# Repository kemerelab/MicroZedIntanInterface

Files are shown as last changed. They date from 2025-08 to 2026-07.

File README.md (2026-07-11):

# MicroZedIntanInterface

An FPGA data-acquisition interface for **Intan RHD2000-style neural recording chips**, built
on a **MicroZed** (Xilinx Zynq-7020) with a custom carrier PCB. The PL talks to up to two
cables of RHD2000 chips over a DDR SPI protocol; the PS streams the data over the network.

- Up to **256 channels @ 30 ksps** (two cables × 128 ch, Intan-standard 12-pin Omnetics, single + DDR).
- A user-programmable per-cable phase delay compensates for cable length.
- **TCP control** (port 0x6900 / 26880) + **UDP data stream** (port 0x6800 / 26624, ~9 MB/s per cable, ~18 MB/s at full config).
- Data path: `Intan ──SPI(DDR)──► PL ──BRAM──► (AXI CDMA) ──► PS ──UDP──► host`.

MicroZed SOMs are ~$300 (e.g. [Newark](https://www.newark.com/avnet/aes-z7mb-7z020-som-i-g-rev-h/eval-brd-32bit-fpga-arm-cortex/dp/62AJ7410)).
The [carrier PCB](pcb/KiCad-Project/) is manufactured at JLCPCB.

<p align="center">
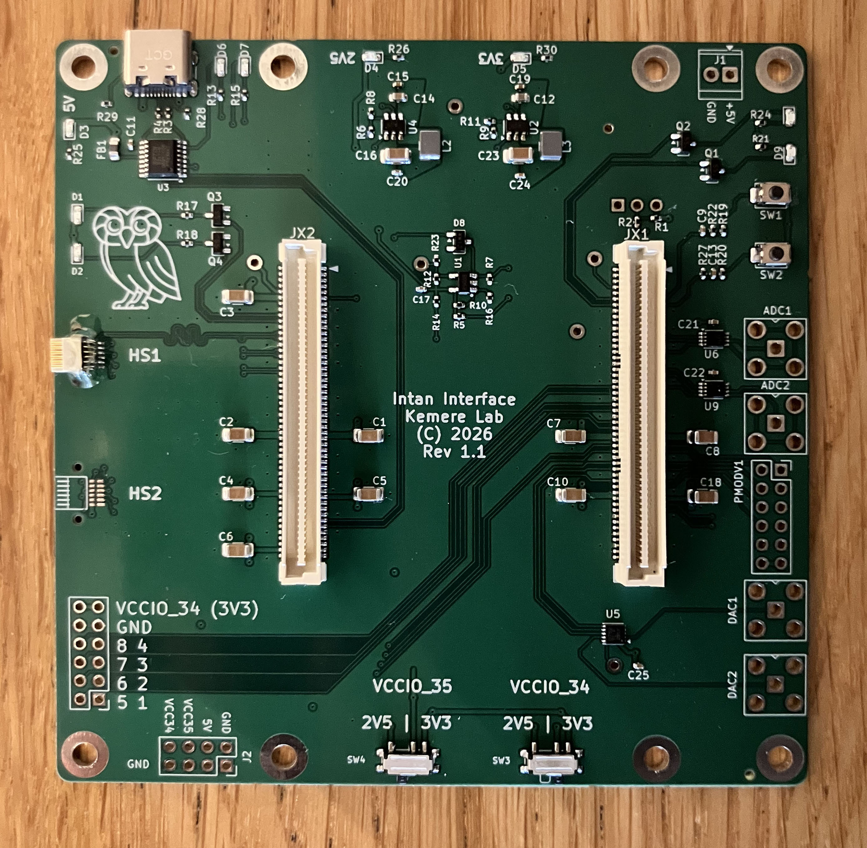
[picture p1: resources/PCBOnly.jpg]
  
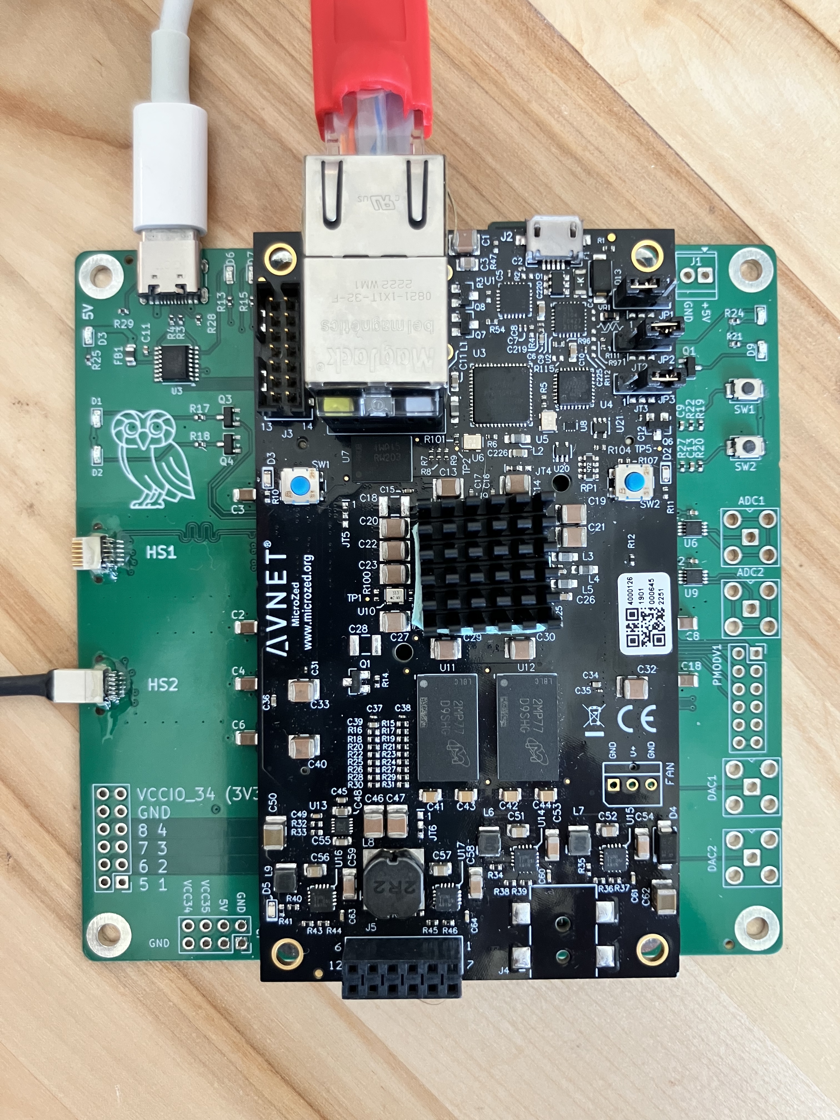
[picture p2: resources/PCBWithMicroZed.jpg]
  
</p>

## Documentation

- **[Getting up and running](docs/getting-started.md)** — assembling the board (Omnetics
  epoxy), the MicroZed boot jumpers, copying the boot image to SD, and building from source.
- **[Command & packet structure](docs/protocol.md)** — the TCP command set, the UDP packet
  format, and the register map.
- **[CLAUDE.md](CLAUDE.md)** — architecture, build commands, and conventions for developers.
- **[ROADMAP.md](ROADMAP.md)** — status and planned work. **[overview.txt](overview.txt)** —
  the deeper architectural narrative.

## Host software

The board's protocol has two reference clients (both speak TCP control + UDP capture):

- **`remote/net.py`** — a single-file Python client for bring-up, cable/phase auto-detection,
  and testing. The human-readable reference for the command set and packet format.
- **[ephys-socket](https://github.com/ckemere/ephys-socket)** — the OpenEphys GUI plugin for
  real recording and visualization (neural + aux/accelerometer channels, fast settle, banked
  aux commands).

<p align="center">
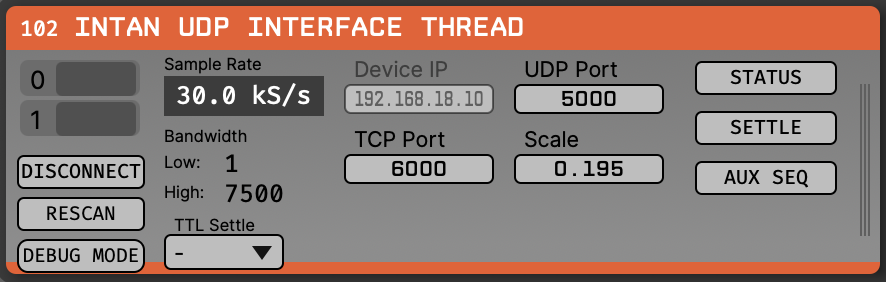
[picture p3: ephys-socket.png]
  
</p>

The firmware (`firmware/`), `remote/net.py`, and the plugin are the **three consumers of the
same register/packet contract** — keep them in sync when changing the protocol.

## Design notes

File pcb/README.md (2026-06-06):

# KiCad design files and production files

The PCB design was dervied from work by Viktor Nokolov licensed under the Creative Commons Zero license. His original project can be found here [https://github.com/viktor-nikolov/MicroZed-carrier-board](https://github.com/viktor-nikolov/MicroZed-carrier-board).

### Revision 1.1 Notes
Board revision 1.1 fixes a power supply bug in 1.0 that prevented the 3.3 and 2.5 V suppplies from workiing.
It also adds two ADCs and two DACs, connected to PL on the VCCIO-34 side.

### Revision 1.0 Notes
Board revision 1.0 fixes the bug in 0.11, and transitions from 2 layer to 4 layer fabrication. This allows for
a smaller and slightly more case-friendly layout (digital IO on the same side of the PCB as Intan/Omnetics 
connectors, and USB-C power moved to the same side as the ethernet connector).

### Revision 0.11 Notes
Board revision 0.11 was used for initial testing. There was an error in the connectivity for the USB-UART
bridge. We fixed this with a bodge that is circled in the image below.

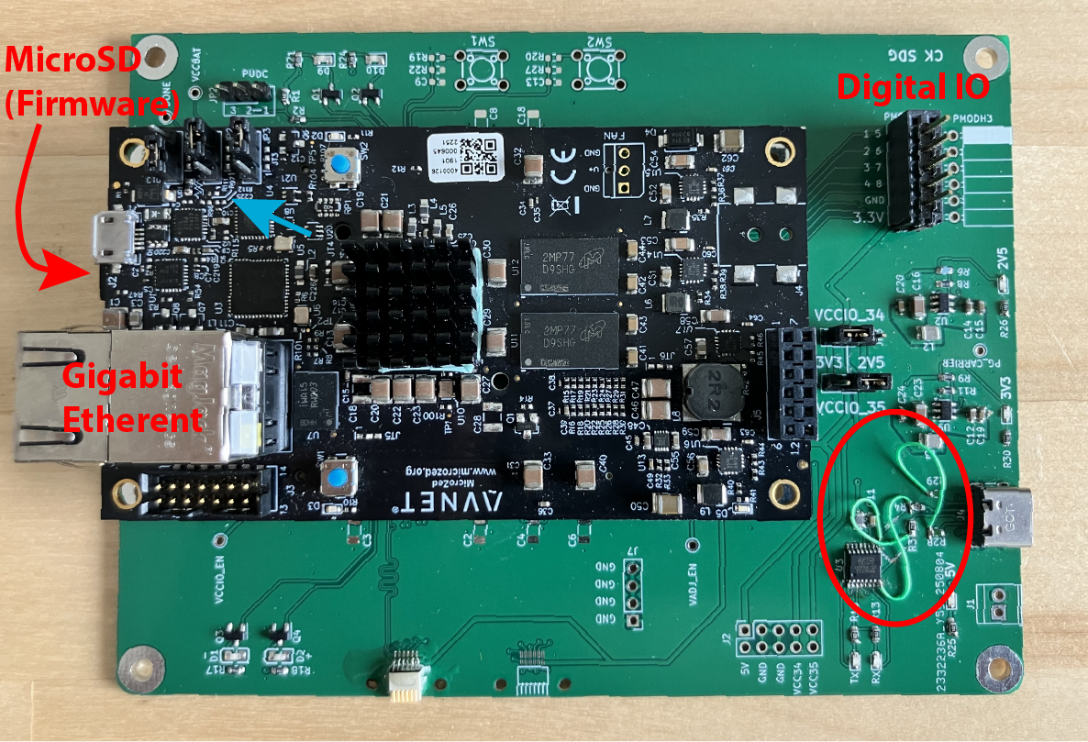
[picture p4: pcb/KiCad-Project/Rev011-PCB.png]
Revision 0.11 Manufactured PCB


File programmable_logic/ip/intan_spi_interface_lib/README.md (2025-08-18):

# Intan SPI Interface Library

This library provides custom SPI interface definitions optimized for Intan RHD chips with dual CIPO channels.
Two interface variants are available: single-ended and differential signaling.

## Interface Variants:

### 1. Single-Ended Interface (intan_spi)
- **VLNV**: kemerelab.org:intan:intan_spi:1.0
- **Signals**: sclk, csn, copi, cipo0, cipo1

### 2. Differential Interface (intan_spi_diff)  
- **VLNV**: kemerelab.org:intan:intan_spi_diff:1.0
- **Signals**: sclk_p/n, csn_p/n, copi_p/n, cipo0_p/n, cipo1_p/n

## Setup Instructions:

### 1. Add to Vivado Project:
- Open your Vivado project
- Go to Settings → IP → Repository
- Click the '+' button to add IP Repository
- Browse to and select this directory: intan_spi_interface_lib
- Click OK and Apply

### 2. Verify Installation:
After adding the repository, you should see "intan_spi_interface_lib" in the IP repositories list.

### 3. Use in Verilog Code:

#### Single-Ended Interface:
```verilog
// Intan SPI Single-Ended Interface
(* X_INTERFACE_INFO = "kemerelab.org:intan:intan_spi:1.0 intan_spi sclk" *)
output wire spi_sclk,

(* X_INTERFACE_INFO = "kemerelab.org:intan:intan_spi:1.0 intan_spi csn" *)
output wire spi_csn,

(* X_INTERFACE_INFO = "kemerelab.org:intan:intan_spi:1.0 intan_spi copi" *)
output wire spi_copi,

(* X_INTERFACE_INFO = "kemerelab.org:intan:intan_spi:1.0 intan_spi cipo0" *)
input wire spi_cipo0,

(* X_INTERFACE_INFO = "kemerelab.org:intan:intan_spi:1.0 intan_spi cipo1" *)
input wire spi_cipo1,
```

#### Differential Interface:
```verilog
// Intan SPI Differential Interface
(* X_INTERFACE_INFO = "kemerelab.org:intan:intan_spi_diff:1.0 intan_spi_diff sclk_p" *)
output wire spi_sclk_p,
(* X_INTERFACE_INFO = "kemerelab.org:intan:intan_spi_diff:1.0 intan_spi_diff sclk_n" *)
output wire spi_sclk_n,

(* X_INTERFACE_INFO = "kemerelab.org:intan:intan_spi_diff:1.0 intan_spi_diff csn_p" *)
output wire spi_csn_p,
(* X_INTERFACE_INFO = "kemerelab.org:intan:intan_spi_diff:1.0 intan_spi_diff csn_n" *)
output wire spi_csn_n,

(* X_INTERFACE_INFO = "kemerelab.org:intan:intan_spi_diff:1.0 intan_spi_diff copi_p" *)
output wire spi_copi_p,
(* X_INTERFACE_INFO = "kemerelab.org:intan:intan_spi_diff:1.0 intan_spi_diff copi_n" *)
output wire spi_copi_n,

(* X_INTERFACE_INFO = "kemerelab.org:intan:intan_spi_diff:1.0 intan_spi_diff cipo0_p" *)
input wire spi_cipo0_p,
(* X_INTERFACE_INFO = "kemerelab.org:intan:intan_spi_diff:1.0 intan_spi_diff cipo0_n" *)
input wire spi_cipo0_n,

(* X_INTERFACE_INFO = "kemerelab.org:intan:intan_spi_diff:1.0 intan_spi_diff cipo1_p" *)
input wire spi_cipo1_p,
(* X_INTERFACE_INFO = "kemerelab.org:intan:intan_spi_diff:1.0 intan_spi_diff cipo1_n" *)
input wire spi_cipo1_n,
```

### 4. Package as IP:
When you package your RTL as IP (Tools → Create and Package New IP), 
the interface annotations will cause the signals to be grouped 
into a single bus interface in block design.

## Troubleshooting:
If you get "Interface VLNV not found" errors:
1. Verify the interface library is added to IP repositories
2. Check that the XML files exist in the correct subdirectories
3. Try refreshing the IP catalog (IP Catalog → Refresh)
4. Restart Vivado if necessary

## Interface Details:
- **Purpose**: Optimized for Intan RHD neurophysiology chips
- **Features**: Dual CIPO channels for enhanced data throughput
- **Type**: Point-to-point interface (1 master, 1 slave)
- **Signaling**: Both single-ended and differential variants supported

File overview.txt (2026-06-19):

Project Overview

Using a Zynq 7000 platform, we have built a system in which the PL acquires data from an SPI-like interface, and then the PS streams it over UDP to a network destination. Control on the network side is a TCP interface. The sampling rate is 30 kHz; a packet is up to 600 bytes at the full 256-channel (two-cable) config, so the data rate is roughly 9 MB/s per cable (up to ~18 MB/s for all 256 channels).

The special SPI protocol involves having two 16 bit words of data are transmitted from the peripheral to the controller (CIPO) an interleaved way on alternative clock phases (double data rate). There are also two CIPO lines. So the whole interface is SCLK, CS, COPI, CIPO0, and CIPO1. Because of the long cables used, the MISO or CIPO data arrives with some phase delay to the clock. The PL handles this by delaying the latching of the CIPO data relative to the COPI data.

The approach that I've adopted in my verilog code for this is the following - I have a main loop with 80 states that runs at 84 MHz. This is a 4x oversampling of the SPI clock rate of 24 MHz. Data is sampled for the first 74 states into a register, and then depending on a phase variable the correctly delayed CIPO data is extracted. The data is put into a FIFO, which copies the data to a BRAM which is used to transmit this data to the PS. This code is in data_generator_core.sv and CIPO_phase_selector.v. This whole loop is repeated 35 times, so that in one data packet, 35 16-bit COPI commands are sent, and 35 x 2 (because of the double data rate) 16 bit data words are read back from each of the 2 CIPO lines. In addition, the PL sends a 64 bit packet magic header and a 64 bit timestamp, plus 64 bits of digital input (8 bits) and other metadata, plus 8 16 bit external ADC values. So one received data packet has 10 32-bit words of packet header plus the data words. The datapath has since been widened to two cables (dual-port), so the channel-enable mask selects among up to 8 streams — regular and DDR for CIPO0/CIPO1 on each of two cables. At the full 256-channel (0xFF) config that is (2 cables) x (2 CIPO lines) x (2 DDR words) x 35 commands = 280 16-bit words = 140 32-bit data words (256 amplifier channels plus per-stream aux/config readbacks), i.e. a 150-word / 600-byte maximum packet.

The PS controls the PL using an AXI Lite register interface. There are control registers which are latched from PS to PL and status registers which are latched from PL to PS. The register names are extracted in data_generator_core.sv, but the register interface is in axi_lite_registers.v. 

The PS code runs on both cores of the processor. One core is dedicated to the serial debug interface, the other core has a fast loop which does three primary tasks: processing commands which might come over from a TCP network endpoint, reading data from the BRAM, and transmitting this data through UDP to the network. The bulk BRAM read is done by an AXI CDMA (a PL bus master that copies each packet from the capture BRAM into a DDR buffer over the S_AXI_HP0 port) rather than by the CPU — this keeps the PS M_AXI_GP master, which corrupts long burst reads, off the data path. The main code files are main.c, network.c, pl_control.c, and pl_dma.c (the CDMA driver), with main.h defining things.

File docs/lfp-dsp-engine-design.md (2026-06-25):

# LFP / on-PL DSP engine — design

Status: **design** (branch `claude/pl-dsp-engine`). This is the agreed plan, not yet
implemented. It captures the first module of an on-fabric **preprocessing engine** aimed
at closed-loop work: a decimating low-pass filter that extracts an **LFP band** and streams
it as a second, independent data product.

LFP = anti-alias low-pass + downsample 30 kHz → **3 kHz** (decimation `R = 10`,
Phase A; was 2 kHz / `R = 15`). See `docs/PHASE_A_SUMMARY.md` for the 3 kHz
anti-alias design (a ~131-tap Kaiser run on a **dual-MAC** time-shared engine,
passband ~1 kHz, ≥46 dB alias rejection) and the analytic-chirp debug signal.
The single-stage budget at R=10 is ~109 taps/256ch per MAC, so the engine now
processes `N_MAC=2` taps/clock (DSP48 is otherwise free); the delay-line BRAM is
unchanged. A CIC÷5 + halfband÷2 variant (`cic_decimator.sv`/`lfp_halfband.sv`)
that would cut the delay-line BRAM ~5× is the documented alternative.

## 1. Why these choices (the short version)

| Decision | Choice | Why |
|---|---|-----|
| Where the filter runs | **PL fabric** | closed-loop needs µs latency; host round-trip is ms |
| Filter structure | **one time-shared polyphase FIR decimator** | ~22 PL clocks per input sample → 1 datapath serves all 256 ch |
| Arithmetic | 1–2 DSP48, per-channel state in BRAM | `taps × out_rate × ch` = `200×2000×256` ≈ 102 MMAC/s ≈ 1.2 DSP48 @ 84 MHz |
| Coefficients | **shared coef RAM, host-loadable via an indirect window** | one design for all channels; not 200+ registers |
| Transport | **separate UDP stream on its own port** | broadband path stays byte-identical; mirrors the Neuropixels AP/LFP split |
| PL→PS | **dedicated LFP BRAM, reuse the existing CDMA** | proven path; CDMA idle 14/15 of the time |
| Packetization | **core 0, one LFP frame per packet (no batching)** | system already sustains 30k pps; batching only enlarges the per-cycle spike and hits the MTU at K=3 |

Bandwidth: LFP is `256 × 2k × 2 B` = **1.0 MB/s** = +6.7% on top of the ~18 MB/s broadband
(the ratio is just `1/R`, invariant of channel count). The real saving comes from *not*
streaming broadband when an experiment only needs LFP (set broadband mask small / 0 →
~18× less data), which the independent-stream design makes a one-register change.

**Data fidelity:** LFP is a *derived* band on a separate wire. The raw broadband samples
are never altered — consistent with the lab's data-fidelity rule.

## 2. Datapath (PL)

```
per-channel sample stream ─► [delay-line BRAM, 256×N] ─► time-shared MAC ─► [decimate ÷R] ─► LFP frame
   (from acquisition FSM)            ▲                         ▲
                                     │                  [coef RAM, 1×N, shared]
                              write @ input rate         read 1 tap/clk
```

- **Delay lines** (the real memory cost): `256 ch × N taps × 16-bit`. For `N=256`:
  256·256·2 = 128 KB ≈ ~28 BRAM36 of 140 on the 7020 (~20%). For `N=200`: ~100 KB. If
  this ever gets tight, switch to **multi-stage** decimation (CIC ÷15 + short comp-FIR, or
  cascaded halfbands) to shrink both the tap count and the delay lines. Single-stage is the
  v1 because it is the simplest to reason about and fits.
- **Coefficient RAM**: `1 × N × 18-bit`, shared across all channels. `N≤512` is half a
  BRAM18. Dual-port: AXI-clock write side, 84-MHz read side (the BRAM *is* the CDC).
- **MAC**: one DSP48E1 (25×18 signed mult + 48-bit acc), time-shared. Sequences
  `(channel, tap)`; emits an output once per `R` input samples per channel.
- **Group delay**: linear-phase FIR → fixed `(N-1)/2 / Fs` ≈ **3.3 ms** at `N=200`. Fine
  for streaming/recording and amplitude/band-power features; a *phase-targeted* closed loop
  (theta/gamma phase-locked stim) would instead want a low-order IIR or a phase predictor —
  noted as a future module, not v1.

## 3. Coefficients — the indirect window (NOT 200 registers)

One filter design is shared by all channels, so there is exactly one coefficient table.
It lives in the coef RAM and is uploaded through a 2-register window, reusing the
**aux-bank strobe/toggle CDC pattern** already in the codebase (`CTRL_REG_AUX_WRITE` +
`CTRL_REG_AUX_STROBE`):

- write pointer auto-increments on each coefficient write;
- the host streams `N` 18-bit signed taps (one-time setup, like the COPI/aux uploads —
  trivial over TCP);
- **coefficients latch only while streaming is stopped** (matches the existing "safe
  control register" convention), so a live pass never mixes old/new taps. A ping-pong
  double-buffer for live retune is a later option, not v1.

The host owns the design: `scipy.signal.firwin`/`remez` → quantize to **Q1.17** (18-bit
signed) → upload. Thin firmware pipe, host computes the physical units — same split as
everywhere else.

## 3a. Sample representation — offset binary (critical)

Intan amplifier samples are **offset binary**: mid-scale `0x8000` = baseline (0 µV),
`V = 0.195 µV × (code − 32768)`. (This repo's debug `sine_lut` confirms it — centered at
`+32767`, "unsigned-16-bit".) The FIR engine is a **pure two's-complement signed** DSP
block, so the offset must be removed at its input and re-applied at its output, otherwise
a quiet baseline sits at the signed saturation rail and the low-pass output is a flat,
saturated line.

Conversion is a symmetric **MSB invert** (`^ 0x8000`), done at the integration boundary so
the engine stays generic and already-proven:
- **in:** `engine_sample = raw_sample ^ 0x8000`  (offset binary → signed, centered at 0)
- **out:** `lfp_sample = engine_out ^ 0x8000`     (signed → offset binary)

LFP is therefore shipped in the **same offset-binary format as broadband**, so the host
de-offsets both identically. The raw broadband stream is untouched (data fidelity).

**Channels filtered = the 32 amplifier converts only** (8 lanes × 32 = 256 ch). The
integration tap drops the 3 aux slots *and* removes the 2-cycle SPI readback offset:
`convert_cmd_sequence` issues CONVERT(0..31) at command-slots 0–31, so with the +2 readback
delay the amplifier samples land at `cycle_counter` 2..33 → fed as engine slot 0..31
(slots 0/1/34 carry aux/wrap and are not fed). This makes the delay line exactly 8×32×N
(not 8×35×N), the ~128 KB / ~32 BRAM36 in §2.

Bonus: debug-mode sine (58–469 Hz, all < 600 Hz) passes the LP filter, so it is a clean
on-bench LFP test signal through this path.

## 4. Contract additions (the three layers)

### 4a. Commands (host → PS), new `0x80` block

| ID | Name | params | notes |
|----|---|---|---|
| `0x80` | `LFP_ENABLE` | p1 = 0/1 | enable/disable the LFP engine + stream |
| `0x81` | `LFP_SET_PARAMS` | p1 = decimation `R`; p2 = `num_taps` | latched while stopped |
| `0x82` | `LFP_SET_CHANNELS` | p1 = 8-bit stream mask | independent of the broadband mask |
| `0x83` | `LFP_WRITE_COEF` | p1 = index (or auto-inc); p2 = 18-bit signed tap | maps to the coef window + strobe |
| `0x84` | `LFP_SET_UDP_PORT` | p1 = port | default 5001 |
| `0x85` | `LFP_DUMP_COEF` | — | optional: read back the loaded table for verification |

### 4b. Control registers (PS → PL), extend past the aux regs (reg 25+)

`PL_N_CTRL_REGS` grows from 25. New regs (indices fixed at implementation):

- `CTRL_REG_LFP_PARAMS` — `[0]` lfp_en, `[15:8]` lfp_stream_mask, `[23:16]` decimation `R`,
  `[31:24]` num_taps (latched while inactive).
- `CTRL_REG_LFP_COEF_ADDR` — write pointer into the coef RAM (read back = current pointer).
- `CTRL_REG_LFP_COEF_DATA` — `[17:0]` tap value; a write stores `coef[ptr]`, `ptr++`
  (crosses to the 84-MHz domain via the aux-style strobe toggle).

> Note: adding control regs moves `STATUS_REG_BASE` (`= PL_N_CTRL_REGS*4`). The binary
> `GET_STATUS` path is index-agnostic so it is unaffected; only raw register peeks shift.

### 4c. get_status (PL/PS → host) — "report everything configurable"

`status_response_t` carries (see `firmware/include/main.h`):

- `lfp_enable`, `lfp_decim_R`, `lfp_lane_mask`, `lfp_num_taps`, `lfp_packets_sent`, `lfp_overrun`.
- `lfp_lane_mask` is reported as the **broadband `channel_enable` mask** (the single source of
  truth) — `network.c::collect_status_data` fills it from `pl_get_current_channel_enable()`,
  not from a separate LFP mask register.

### 4d. LFP UDP packet (board → host, port 5001) — **PL-built, DMA'd into the pbuf**

Compact, self-describing, its own magic so a misrouted packet is caught. **The PL builds the
complete wire packet (6-word header + decimated samples) in the LFP output BRAM** — exactly
the broadband pattern where `data_generator_core.sv` writes the 10-word header into the
capture BRAM. The PS then just **CDMAs the whole frame straight into a pbuf and sends it**
(`network.c::lfp_stream_service` → `pl_dma_read_addr` from `0x84000000` into a non-cacheable
LFP staging buffer → `udp_sendto` a `PBUF_REF`). **No PS-side header construction, no
`Xil_In32` sample loop** (`scripts/check_dma.sh` enforces this — the LFP single-beat loop is
gone). Implemented layout (one frame = one wire packet):

| words | field | notes |
|---:|---|---|
| 0 | magic low `0x1F1FBEEF` | distinct low word vs broadband's `0xDEADBEEF` |
| 1 | magic high `0xCAFEBABE` | |
| 2–3 | 64-bit master **timestamp** | the master count of the **newest broadband sample in this output's decimation window** — i.e. the most recent broadband packet that was clocked into the filter bank for this output. The decimating filters are just FIR: when one emits an output, exactly one real, already-acquired broadband sample is the newest input in that output's support, and this is its master count (the *same* counter the broadband header stamps, word 1). For frame `m` at total decimation `R` it is broadband packet `R·m + (R−1)` (e.g. R=10 → `10m+9`). Causal, monotonic, `R` apart — an **absolute master timestamp**, not a frame index. (See "timestamp accounting" below for the CIC→halfband bookkeeping.) |
| 4 | `[7:0]` lane_mask · `[15:8]` decim_R · `[23:16]` num_taps · `[31:24]` overrun | `lane_mask` = the **broadband `channel_enable` mask** (single source of truth; see below) |
| 5 | 32-bit sequence number | PL-maintained LFP frame counter (++ per emitted frame), for drop detection |
| 6… | payload: enabled lanes × 32 ch × 16-bit, offset-binary (2 per word) | `0xFF` → 256 ch = 128 words |

**Lane mask = broadband mask.** The LFP engine's `lane_mask` is driven from the broadband
`channel_enable_reg` (`data_generator_core.sv` → `dsp_channel_enable` → `lfp_dsp_block`), **not**
from `lfp_cfg[15:8]`. The LFP filters exactly the broadband-enabled lanes — one place to pick
streams (`set_channels`). `CMD_LFP_SET_CHANNELS` is deprecated (firmware accepts-and-ignores).

**Timestamp accounting (CIC→halfband).** The chain is CIC(/5) → halfband(/2) = /10, each a
decimating FIR. Trace one output's *newest input* through the cascade:
- The CIC emits an output frame on every 5th broadband `packet_tick` (`run_comb` when
  `decim_cnt` wraps at R=5), so CIC output `k` has newest broadband packet `5k+4`.
- The halfband ingests one sample per CIC output and emits on every 2nd one (`decim_phase`),
  so halfband output `m` has newest CIC input = CIC output `2m+1`, i.e. newest broadband
  packet `5·(2m+1)+4 = 10m+9`.

`lfp_dsp_block` keeps a single register `ts_ingest`, updated to `(master_timestamp − 1)` on
**every** broadband `packet_tick` (the live counter has already incremented to "just-finished
packet + 1" on that edge, so `−1` is the count the broadband header carries for that packet).
On `frame_tick` (the halfband's decimation tick / `start_pass`) it snapshots `ts_ingest` into
the header. The cascade latency from "packet `10m+9` closes the window" to "`frame_tick` fires"
(CIC comb pass + glue replay) is a few hundred clk — far less than the ~2800-clk broadband
packet period — so **no new `packet_tick` arrives in between**, and the snapshot is exactly
`10m+9`. (If the engine ever fell a frame behind under load, `compute_overrun` latches and is
reported in header word 4 bit 24.)

**Host alignment.** The stamp marks *which broadband sample is the newest one folded into this
LFP value* — it is **not** the instant the LFP value represents. A linear-phase anti-alias
filter's output is centered earlier than its newest input by the chain's **group delay** (a
fixed, known number of broadband samples). To align an LFP sample with the broadband stream's
*content*, subtract that group delay; to align with *which input data has been seen*, use the
stamp directly. The plugin exposes this as a second ~3 kHz DataStream (`A_LFP1…`, `B_LFP1…`),
alongside the 30 kHz broadband stream.

## 5. PL plumbing summary

Reuses proven parts; the only new RTL is the filter:

1. **+1 BRAM** — small LFP ring (a few KB), written by the DSP engine (kept separate from
   the `0x80000000` capture BRAM to isolate the two write paths).
2. **+1 `axi_bram_ctrl`** at a new address (e.g. `0x84000000`), added as a 3rd slave on
   `smartconnect_1` (2×2 → 2×3) — a copy of the existing pattern.
3. **Reuse the one CDMA** — broadband transfer every 33.3 µs cycle (as today) + an LFP
   transfer on the 1-in-`R` cycle (different `SRCADDR`). Single engine, sequenced, no
   contention (LFP duty 1/decim, each transfer a few µs). The LFP output BRAM
   (`0x84000000` / `axi_bram_ctrl_1`) is in the `axi_cdma_0/Data` address space
   (`design_1_bd.tcl`) so the CDMA can read it; `pl_dma_read_addr(dst, src_addr, n)`
   generalizes the read to an arbitrary BRAM source.
4. **+1 `XAxiCdma_SimpleTransfer`** call (the whole PL-built packet, header + samples) →
   zero-copy `udp_sendto` in the core-0 loop. The PS adds **no** header and copies **no**
   samples on the CPU.

## 6. Out of scope for v1 (future engine modules)

- Multi-stage (CIC + comp-FIR) decimation if BRAM/taps get tight or more bands are added.
- IIR / phase-predictor path for phase-targeted closed loop.
- Live coefficient retune (ping-pong double-buffer).
- Core-1 as a data engine — only worth it bundled with moving serial debug to a **soft
  core** (the EMAC is a single core-0-owned peripheral and bare-metal lwIP is single-
  instance, so core 1 can't independently transmit; parked).
- On-fabric feature extraction (band power, threshold crossings, phase) feeding a control
  output — the actual closed-loop endgame this engine is built toward.

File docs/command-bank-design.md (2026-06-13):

# Design — Aux Command Bank Rebuild + Fast-Settle/Digout Override

**Status:** Converged design (June 2026). Confirm chip details against
`docs/Intan_RHD2000_series_datasheet.pdf` / `docs/Intan_RHD2164_datasheet.pdf` before implementing.
Reference implementation studied: `github.com/open-ephys/rhythm` + `open-ephys-plugins`
(clones under `~/Code/Intan/`).

## Motivation

Today the streaming command stream is a flat, fixed 35-entry list replayed identically every
packet (`pl_control.c: convert_cmd_sequence`, played out by `data_generator_core.sv` over
`cycle_counter` 0..34). The three aux positions are static `CONVERT(32/33/34)`, leaving no room —
without a firmware rebuild — for temperature, supply, runtime link/health checks, impedance,
ad-hoc register access, real-time digital output, or fast settle.

This rebuild replaces the static aux positions with **programmable, looping, swappable per-slot
command banks**, adds a **real-time override layer** (fast settle + digital-out + a Register-3
shadow), and uses **PL-side frame alignment with command-echo identity** so the host receives
clean, self-contained UDP packets.

## Command source model

Per packet (= one ~30 kHz sample) the PL issues 35 commands: 32 channel converts + 3 aux.
A host-writable **full 35-entry command table** remains the base; two enable bits overlay the
segmented behavior:

```
if (cycle_counter < 32)
    cmd = auto_convert_en ? make_convert(cycle_counter)    // CONVERT(pos), fixed every packet
                          : full_cmd_table[cycle_counter]; // host table (init/cal/cable-test)
else begin
    slot = cycle_counter - 32;                              // 0,1,2
    cmd = aux_bank_en ? aux_slot[slot].read()              // looping per-slot bank
                      : full_cmd_table[cycle_counter];
end
// → override layer (below) may rewrite cmd
```

| Mode | `auto_convert_en` | `aux_bank_en` | `loop_count` | Behavior |
|---|---|---|---|---|
| Init / calibrate / cable-test | 0 | 0 | 1..N | full table replayed (today's exact pipeline) |
| Acquisition | 1 | 1 | 0 (∞) | auto converts + looping aux banks + overrides |

The segmentation is a **two-index-domain** FSM: positions 0–31 indexed by `cycle_counter` (fixed
each packet); positions 32–34 indexed by **per-slot, per-packet indices** that loop independently.

## Storage: 3 independent per-slot command BRAMs

One **dual-port BRAM per aux slot** (3 total) — *not* one shared 3×N array — so each slot's index,
length, and bank-select are fully independent (Slot 2 loops at 3, Slot 3 at ~30; trivial with
separate RAMs). Each BRAM is its own AXI **memory-mapped window** (PS writes as memory; FPGA reads
on the PL clock), separate from the control registers and the data BRAM.

- **≥2 banks per slot** (active + standby), so you write a standby bank while the FSM reads the
  active one — no torn program.
- **Length is bound to the bank.** Each bank carries its own `(loop_idx, end_idx)`, so a
  bank-select **atomically swaps the length too**. (Intan keeps length per-*slot* — a footgun we
  fix; their AuxCmd3 banks have different lengths and must be hand-synced on every swap.)
- **Per-slot index** advances once per packet, wrapping `end_idx → loop_idx`.
- **Atomic swap:** PS writes `aux_bank_select[slot]`; the FSM latches it only at a packet boundary.
- **Confirm-before-reuse handshake:** PS polls `aux_bank_active[slot]` (status reg) until it reads
  the new bank → the freed bank is now safe to write.
- **Read needs prefetch:** BRAM read has 1–2 cycle latency, so issue the `(bank,index)` address a
  state ahead inside the 80-state loop (plenty of slack).

**Multi-chip note:** one shared COPI broadcasts to both chips, so aux commands are **shared** — one
set of 3 banks, not per-chip. Each chip returns on its own CIPO line. So *identity = echoed command
(what) + CIPO line (which chip)*; no per-chip bank machinery (unlike Intan's per-port banks).

## Slot allocation (final)

| Slot | Role | Default contents | Reg writes |
|---|---|---|---|
| **1 — real-time control** | digital-out (GPIO→`auxout` mirror) + fast settle | `WRITE(3,…)` every packet (digout); fast settle hijacks it on TTL edges | **sole Reg 0 + Reg 3 writer** (via shadow) |
| **2 — ADC only** | accelerometer sweep | `CONVERT(32) → CONVERT(33) → CONVERT(34)` looping → each aux input at **10 kHz** | none (pure reads) |
| **3 — config + measurements** | setup + low-rate housekeeping, banked | bank A = register config/calibration (run once); bank B = supply `CONVERT(48)`, temp read `CONVERT(49)`, link/chip-ID `CONVERT(63)`/`RegRead(40-44)`, arbitrary R/W, looping (length ~30) | many regs, time-exclusive |

This gives all goals at once: real-time digout, dedicated 10 kHz accel, and temp/supply/link +
config — no rate compromise. (Intan instead crams accel+temp+supply into one slot → 7.5 kHz accel;
dedicating Slot 2 beats that.)

## Override layer + the Register-3 shadow

Two RHD registers are shared across functions, and RHD writes set **all 8 bits at once**, so we
maintain coherent **shadows** and override any write to those registers — generalizing the trick
Intan already uses (override bit 5 on Reg-0 writes; `digout_override` on Reg-3 writes):

**Register 0 — ADC config + amp fast settle** (`D5` = amp fast settle):
- Force `D5` = live fast-settle state on *any* `WRITE(0,…)`.
- On a fast-settle TTL **edge**, replace **Slot 1's** command with `WRITE(0,0xFE)` (on) / `0x80DE`
  (off). Chip latches Reg 0 → two injections per pulse.

**Register 3 — temp sensor + auxiliary digital output** (`D0`=digout, `D2..D4`=tempen/tempS1/tempS2):
- Maintain `reg3_shadow = { static MUX/HiZ bits, tempen/tempS state, live digout bit }`.
- The **digout bit** = a software-selectable TTL/GPIO input (real-time mirror to the headstage
  `auxout` pin — this is why Intan hardcodes it: `auxout` follows a controller GPIO at ~1-sample
  latency, `main.v:1252` routes `TTL_in[channel]` → `digout_override`).
- Override *any* `WRITE(3,…)` (from any slot) with `reg3_shadow` → no slot can clobber another's
  Reg-3 bits; Reg 3 has a single coherent authority.

**Temperature accuracy (decision):**
- *Single-point* (default): fix `tempS` in the shadow, one `CONVERT(49)`. No sequencer.
- *Differential* (Intan-accurate): a small temp sequencer steps `tempS` in the shadow in sync with
  Slot 3's `CONVERT(49)`. Add only if calibrated temperature is needed.

**DSP reset** (optional digital fast settle): force the CONVERT **LSB ("bit H")** on `CONVERT(0..31)`
from software and/or a selectable pin — in-place, drops no data. Independent of amp settle.

**Invariant:** the override layer only ever *replaces* commands in **Slot 1** (the real-time-control
slot). Slots 2 (ADC) and 3 (measurements/config) are never command-replaced — only Reg-write *bits*
are coherently substituted. So the 10 kHz accel stream and the measurement stream are never perturbed.

## Data path — align in the PL, echo the command, self-contained packets

Intan resolves the SPI **2-command pipeline delay in the FPGA** (a tuned offset — `channel_MISO<=33`,
"*Bug fix: changed 2 to 33*" — plus fixed-order frame assembly), so the host reads clean, grouped
frames; it does **not** ship shifted data or read wrapped points. (The exact cycle-level grouping is
intricate and empirically tuned; verify ours by simulation rather than by replicating their magic
offset.) We do the same:

- **`aux_capture` unit:** latch each aux result, pair it with the **originating command** carried
  through the readback delay, and emit clean.
- **Command-echo identity:** each packet's metadata carries the *originating command* per aux slot.
  The command is self-describing (`CONVERT(49)`→temp, `CONVERT(48)`→supply, `CONVERT(3x)`→accel
  axis, `READ(addr)`→that register). Host decodes with **zero** knowledge of the loaded program,
  and a dropped packet never desyncs. Robust to bank swaps too.
- **Self-contained UDP packets:** unlike Intan (continuous, reliable USB), we're on lossy UDP, so
  each packet must stand alone. Aligning in the PL gives this directly; if any result still wraps,
  pad with trailing dummy command(s) so only don't-care results cross the boundary.

## Packet metadata

Fill the header words currently `0x0` (`data_generator_core.sv:352`). Per packet:
- per protected slot: the **echoed originating command** (+ optional per-slot index for drop
  detection) — identity for the aux results on each CIPO line.
- `fast_settle_active` (1 bit), `digout_state` (1 bit), optional `slot3_bank`.
- reserved space for PS-side **BNO055 IMU** quaternion/accel (read over Zynq PS-I²C; see
  `[[openephys-accelerometer]]` — dedicated SDA/SCL on the cable, not in these slots).

## Aux command format (verified Intan interface → our adaptation)

Intan: 3 dual-port RAMs (`RAM_bank_1/2/3`, `main.v:937/972/994`), each 16 banks × 1024 × 16-bit
RHD command words; read at `RAM_addr_rd = aux_cmd_index_N`, `RAM_bank_sel_rd = bank`; written
word-by-word via WireIns `WireInCmdRamData/Addr/Bank` (0x07/0x05/0x06) + `TrigInRamWrite` (0x42)
bit 0/1/2 selecting the slot (`uploadCommandList`). Bank via `selectAuxCommandBank`, length via
`selectAuxCommandLength`.

Ours: same model, adapted — **memory-mapped BRAM window per slot** (cleaner than wire+trigger on
Zynq), **one bank-select per slot** (shared COPI, not per-port), **length bound to the bank**,
much smaller (2–4 banks, N≈30).

## Host API (new `CMD_*` in `net.py` + firmware)

| Command | Action |
|---|---|
| `AUX_BANK_WRITE(slot, bank, list)` | upload a program (incl. its length) into a standby bank |
| `AUX_BANK_SELECT(slot, bank)` | atomic swap at next packet boundary (carries the bank's length) |
| `READ_REGISTER(addr)` / `WRITE_REGISTER(addr,val)` | one-off, injected via Slot 3 (or Slot 1 for Reg 0/3 through the shadow); result tagged |
| `SET_FAST_SETTLE(pin, amp_en, dsp_en, mode)` | configure the Reg-0 override |
| `SET_DIGOUT(pin, enable)` | select the GPIO mirrored to `auxout` |

## PL module boundaries (separately testable in xsim)

| Module | Responsibility | Testbench |
|---|---|---|
| `aux_command_bank.sv` | per-slot BRAM + banks; advance index; emit command; atomic bank/length swap | load banks → clock N packets → assert command sequence, wrap, atomic swap+length |
| `override_layer.sv` | Reg-0 bit5 / Reg-3 shadow / digout / DSP bit-H; Slot-1-only replacement | feed commands + TTL edges → assert Slot-1-only replacement, shadow coherence, invariant |
| `aux_capture.sv` | pair results with originating command across the readback delay; emit labeled triples | synthetic delayed results → assert correct command↔result pairing incl. boundary |
| `data_generator_core.sv` | compose: auto-convert / table / banks → override → COPI; capture → frame | integration TB |

## Three-layer contract changes (keep in sync — CLAUDE.md)

- **PL:** new `aux_command_bank.sv`, `override_layer.sv`, `aux_capture.sv`; auto-generate
  `CONVERT(0..31)`; per-slot BRAM windows + bank-select/active status; fast-settle/digout config;
  Reg-3 shadow; command-echo metadata.
- **PS** (`main.h`, `pl_control.c`): bank upload/select + confirm handshake; `READ/WRITE_REGISTER`;
  fast-settle/digout config; `status_response_t` additions (active banks, fast-settle/digout state).
- **Host** (`net.py`): bank programming; command-echo decode; new `CMD_*`; packet-size update.

## Resolved / open

- ✅ Decode = **command-echo** (self-describing), align in PL, self-contained packets.
- ✅ Storage = **3 independent per-slot BRAMs**, ≥2 banks, **length bound to bank**, double-buffer swap.
- ✅ Slots: 1 = real-time digout+fast-settle (Reg-3 shadow), 2 = ADC-only accel @ 10 kHz,
  3 = config + supply/temp/link (banked).
- ✅ Reg 3 sharing resolved by a coherent **shadow + override**.
- ☐ Bank depth (banks/slot) and Slot-3 housekeeping length N (≈30) — finalize.
- ☐ Temperature: single-point (default) vs differential (needs a temp sequencer).
- ☐ Impedance: implement as a swap-in bank (Zcheck DAC) on a slot, or defer to its own epic.

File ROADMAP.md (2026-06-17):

# Roadmap — toward a feature-complete Intan acquisition system

Working TODO list for the MicroZed/Intan DAQ. Grouped into epics; check items off as
they land. Chip-feature details should be confirmed against the datasheets in `docs/`
(`Intan_RHD2000_series_datasheet.pdf`, `Intan_RHD2164_datasheet.pdf`) before implementing.

Remember the three-layer contract: every register/packet change touches
`programmable_logic/` (PL), `firmware/include/main.h` + `pl_control.c` (PS), and
`remote/net.py` (host). See CLAUDE.md.

---

## A. Intan chip feature-completeness (expose RHD2000 capabilities)

- [x] **Fast settle — software trigger** — amp fast settle = write reg 0 bit 5: `0x80FE` on,
      `0x80DE` off (datasheet pulse ~2.5/fH). Optional DSP-reset variant = OR the CONVERT LSB
      ("bit H") to reset the digital high-pass filter. *(top 5)*
      **Done 2026-06-11** (`claude/aux-seq-v2`: `override_layer.sv` + `CMD_SET_FAST_SETTLE`;
      pulse duration is host policy). Sim-verified; needs on-hardware validation.
- [x] **Fast settle — GPIO trigger** — software-selectable `digital_in_0[*]` pin, edge-triggered
      injection of `0x80FE`/`0x80DE` into one aux command slot (Intan-style: preserves throughput
      except on transition packets). Refs: `data_generator_core.sv:273,312`; Intan
      [`rhythm/main.v`](https://github.com/open-ephys/rhythm/blob/master/main.v)`:750-767,1028-1030`.
      **Done 2026-06-11**: pin software-selectable (`fast_settle gpio <pin>`), level sampled
      once per packet, edge → one injection packet each way; DSP bit-H independent (sw or pin).
      **RESOLVED (was OPEN):** the injection *replaces Slot 1's command* on transition packets
      (the design doc's Slot-1-only invariant) — Slot 1 is the real-time-control slot whose
      default program is just a Reg-3 carrier, so Slots 2/3 (accel, housekeeping) are never
      perturbed; the only loss is one digout refresh on the transition packet.
- [x] **Digital output (`auxout`) — GPIO mirror** — drive the chip's `auxout` pin from a
      software-selectable controller GPIO in real time (Slot 1 Reg-3 override; confirmed Intan
      `main.v:1252` routes `TTL_in[ch]` → digout bit). Pairs with the Reg-3 shadow.
      **Done 2026-06-11**: Reg-3 shadow (host-owned D7..D1 + live D0), any-slot WRITE(3)
      coherence, `CMD_SET_DIGOUT` / `digout gpio <pin>`. ~1-packet latency.
- [ ] **Configurable amplifier bandwidth** — upper/lower cutoff registers (RH1/RH2/RL),
      host command + firmware sequence instead of the hardcoded init.
- [ ] **DSP high-pass / offset removal** config (register 0 DSP cutoff bits).
- [ ] **ADC self-calibration** command exposed to host (currently buried in the init blob).
- [ ] **Aux ADC inputs** — read aux1/aux2/aux3 (temperature sensor, supply voltage) and
      surface them in the packet + status.
      *Mechanism done 2026-06-11*: slot-2 default = accel sweep @10 kHz, slot-3 default =
      supply/temp/chip-ID loop; results land in packet words 34/0/1 labeled by command echo.
      Remaining: host-side scaling/labeling into engineering units (°C, V) + recording format.
- [ ] **Impedance testing** — test-current injection + capacitor-DAC select (regs 5/6/7),
      host workflow to sweep electrode impedance.
- [ ] **ADC format config** — two's-complement vs offset-binary, absolute-value mode.
- [ ] **Configurable digital inputs** capture into the packet (`:273` TODO).
- [x] **Generalize COPI sequences** — replace the hardcoded `convert`/`init`/`cable_test`
      blobs in `pl_control.c` with host-configurable, **looping aux command banks** + a
      fast-settle override layer. **Design: [`docs/command-bank-design.md`](docs/command-bank-design.md).**
      This is the foundation the fast-settle items (above) and impedance/temp/supply build on.
      **Done 2026-06-11** (`claude/aux-seq-v2`): `aux_command_sequencer.sv` — 3 slots, 2 banks
      each, length bound to bank, atomic packet-boundary swap, live bank upload + confirm
      handshake, one-shot injection for runtime register R/W (`CMD_READ_/WRITE_REGISTER`),
      command-echo identity in the packet header. Default OFF — datapath proven bit-identical
      to main when disabled. See `docs/NIGHT_LOG-2026-06-11.md`.
      *(Init/calibration/cable-test keep the legacy full-table path by design — they run while
      stopped; the banks cover the streaming-time use cases.)*

## B. Board-rev sensor / IO interfaces (2 ADC + 2 DAC + 9-axis IMU)

- [ ] **ADC SPI master** (new PL module) — develop test-first in sim against the
      converter datasheet timing. + testbench.
- [ ] **DAC SPI master** (new PL module) + testbench.
- [ ] **AXI registers** — DAC setpoints (PS→PL), ADC config; wire into `axi_lite_registers.v`.
- [ ] **Integrate 2 ADC samples into the packet** — fills the external-ADC metadata slots
      that are currently `0x0` (ties into Epic C).
- [ ] **Firmware control API + host commands** for DAC output / ADC config.
- [ ] **Constraints/pinout** for the new board revision (`programmable_logic/constraints/`).
- [ ] **9-axis IMU (BNO055) — absolute orientation.** I²C sensor; on-chip fusion outputs
      quaternion / Euler / linear-accel / gravity / temp / calibration. Read via the **Zynq PS
      hard-I²C (EMIO)** — mostly firmware, little/no new PL RTL — and stamp ~100 Hz into packet
      metadata (Epic C). **Physical layer (proven by the OE 3D headstage):** RHD2164 DDR uses a
      *single* MISO pair, so the **second MISO pair's two cable conductors are repurposed as
      dedicated SDA/SCL** (12-pin Omnetics: pin3=SDA, pin4=SCL). Our system uses the same DDR
      topology → same cable trick applies. Refs:
      [low-profile-headstage-64ch-3d](https://github.com/open-ephys/low-profile-headstage-64ch-3d)
      (RHD2164+BNO055 schematic); host decode
      [acquisition-board](https://github.com/open-ephys-plugins/acquisition-board) `AcqBoardONI.cpp`.
- [ ] **(Free win) Analog accelerometer via aux** — an ADXL335 on auxin1/2/3 is already captured
      by `CONVERT(32/33/34)`; needs only host-side decode/labeling (see Epic A aux item).

## C. Packet / metadata payload completion

- [ ] **Fill header words 3–4 + the 8 external ADC values** (presently hardwired `0x0`).
      Ref: `data_generator_core.sv:352` breadcrumb.
- [ ] **64-bit non-neural metadata state** in the exfil FSM (fast-settle flag, digital in,
      discrete-ADC values, IMU quaternion/accel, status).
- [ ] **Keep the 3-layer contract in sync** (PL ↔ `main.h` ↔ `net.py`).

## D. PL→PS throughput / DMA

- [x] **Characterized the path** — `get_status` reports per-packet CDMA and
      receive→transmit time (raw global-timer ticks; host converts to µs). At 0xFF
      (2 cables): ~3 µs typ / ~10 µs max of the 33.3 µs budget, of which the CDMA is
      ~1–2 µs. Lots of headroom (analysis says ≤4 cables is comfortable PS-side).
- [x] **DMA implemented — AXI CDMA, BRAM→DDR over S_AXI_HP0** — a PL master reads the
      capture BRAM and writes a non-cacheable DDR buffer, taking the corrupting PS
      M_AXI_GP master off the bulk-read path (this is what fixes the 0xFF dual-port
      dropout). Read-path logic proven in sim (`programmable_logic/sim/run_axi_read_sim.sh`);
      decided against a custom `axi_bram_ctrl` (`docs/custom_axi_bram_ctrl_decision.md`).
      Driver: `firmware/src-core0/pl_dma.c`.
- [ ] **Double-buffer (pbuf ring) + interrupt** to replace the polled single staging
      buffer. Not needed for ≤4 cables (the CDMA is ~free in the budget); revisit for
      higher channel counts or to free core 0.
- [x] **Benchmarked vs the old CPU read** — the old long-burst GP read corrupted 0xFF;
      the CDMA is clean at full bandwidth, in-spec at 131.25 MHz. Win observable via
      `get_status`.

## E. Firmware robustness / networking

- [ ] **Hotplug + DHCP** — finish lwIP hotplug init and add a DHCP/discovery option.
      Refs: `main.c:421-422`.
- [x] **Fix the 10 ms print timeout** that stalls RX (`shared_print.c:163`).
      **Done 2026-06-13 (`claude/dual-port`):** `send_message()` is non-blocking (drops +
      counts instead of the 10 ms spin); routine status moved off the print ring onto a
      shared-memory snapshot that **core 1** formats/prints (core 0 only does cheap binary
      stores), so status reporting never stalls the data pump. Fixed the "`get_status` adds
      2-7 packet errors while streaming" symptom that surfaced at the dual-port packet size.
- [ ] **Error-state recovery** — track timestamp-gap duration on recovery (`main.c:143`).
- [ ] **De-hardcode IPs** — config mechanism instead of baked-in 192.168.18.x.

## F. OpenEphys integration (`ephys-socket` plugin)

Target: [`ckemere/ephys-socket`](https://github.com/ckemere/ephys-socket) (clone at
`~/Code/ephys-socket`) — a forked OpenEphys "Ephys Socket" `DataThread`, already MicroZed-specific
(`IntanInterface` = UDP recv + TCP control; `IntanSocket` = parse → GUI buffer). It is the **third
consumer of the register/packet contract** (after firmware and `net.py`) — `IntanInterface`
duplicates `net.py`'s `CMD_*` set.

Current gaps (plugin is WIP):
- [x] **Packet alignment** — reads data flat (`dataWords[ch/2]`, `IntanSocket.cpp:481`) with **no
      +2 pipeline shift** and ignores metadata words [6–9]. Needs the PL-side alignment +
      command-echo (Epics A/C) to get correctly-labeled neural + aux channels.
      **Done**: `fix/channel-reorg-aux-deskew` added the +2 de-skew + stream de-interleave;
      `claude/aux-test-tooling` adds the command-echo decode (header words 4/5).
- [x] **Aux split + scaling** — allocates 3 aux/bank + `aux_data_scale` but doesn't actually
      separate/align them; wire to the echo metadata.
      **Done 2026-06-12** (`claude/aux-test-tooling`): per-packet flag-driven parse — legacy
      cycles 34/0/1 vs sequencer-mode echo-identified accel de-interleave (1 axis/packet,
      sample-and-hold). Absolute aux calibration (engineering units) still pending.
- [x] **Command parity (testing subset)** — add the new `CMD_*` (aux bank write, fast settle,
      digout, register R/W) to `IntanInterface`, in lockstep with `net.py` + firmware.
      **Done 2026-06-12** for bank write/select/seq-en, fast settle, READ_REGISTER + 98-byte
      status, with GUI controls (STATUS / SETTLE / AUX SEQ buttons, TTL-settle dropdown — all
      live during acquisition). Remaining: SET_DIGOUT and WRITE_REGISTER are defined as command
      IDs but have no GUI affordance yet.
- [ ] **Contract single-source** (see Epic H) — make the plugin consume the generated
      packet/register/`CMD` definition so all 3 consumers stay in sync. *This is the real coupling.*

Integration approach (must stay installable via the OpenEphys Plugin Installer, which requires a
standalone repo + releases):
- [ ] **Decide submodule vs subtree** for co-locating in this repo:
      - *Submodule* (recommended): plugin stays its own repo (source of truth, installable); this
        repo references it at e.g. `openephys-plugin/`. Standard, low-risk; bump pointer on change.
      - *Subtree*: plugin code lives in this repo (primary dev); `git subtree push` to the
        standalone repo to cut installable releases. Smoother co-dev, more arcane.
      - Either way the standalone repo + its CMake/CI/releases persist for installability.
- [ ] **Build + docs** for the plugin within this repo.

## G. Verification infrastructure (scoped to where iteration cost is highest)

- [ ] **RTL elaboration/synth smoke check** — cheap; catches width/latch/multi-driver/loop
      errors in minutes. Run on every RTL change.
- [ ] **Testbenches for NEW modules** — ADC/DAC SPI masters, the DMA datapath, packet
      packing. (Not the proven legacy datapath.)
- [ ] **Python mock board** — UDP packet generator + TCP responder so `net.py`'s
      `DataValidator`/`CableDetection` run with no hardware.
- [ ] **Host-side unit tests** — pure logic (`calculate_packet_size`, struct unpacking).
- [ ] **Native-gcc firmware unit tests** for pure logic (packet-size math, struct packing).

## H. Maintainability

- [ ] **Single-source register/packet contract** — one definition that generates the PL
      params, `main.h` offsets, and `net.py` constants. Kills hand-sync duplication.
- [ ] **Fix CLAUDE.md toolchain path** — tools are at `/opt/Xilinx/2025.1/`, not `~/Xilinx/`.
- [ ] **Build/CI smoke** — scripted elaborate + firmware compile (`scripts/clean_build_all.sh`
      already does a full Vivado→XSA→Vitis build end-to-end).

## I. Second cable interface (dual headstage port)

The carrier PCB has a **second Omnetics connector already routed to the FPGA** with its own
SPI signals (CS=IO_L15, SCLK=IO_L17, COPI=IO_L19, CIPO1=IO_L22, CIPO2=IO_L24) — so this is a
PL→firmware→host→plugin job, **no board respin**. A second cable doubles channel capacity
(up to 256 ch) but also doubles the PS→UDP stream (~9 → ~18 MB/s), which is the main risk and
the reason to validate the memory bus first. **Common command set initially** (one acquisition
FSM, master outputs fanned out to both ports' pins), but **independent per-port cable length /
phase** from the start. Keep default-OFF / bit-identical to the single-port path when the
second port is disabled, the same discipline used for the aux sequencer.

- [x] **Phase 1 — datapath + bandwidth characterization (debug mode).** Widen the FIFO word
      64→128-bit `{cipo3,cipo2,cipo1,cipo0}`, extend `channel_enable` 4→8 bits + per-port phase
      regs, extend the packet format and the three-layer contract (`main.h`/`pl_control.c`/
      `net.py`). Have **debug mode synthesize port-2 data** so packets are full doubled size,
      then measure whether PS core-0's BRAM-poll + lwIP UDP loop sustains ~18 MB/s. No real
      CIPO-capture risk yet — pure datapath/throughput. Feeds, and is gated by, **Epic D**.
      **RTL/firmware/host DONE 2026-06-13 (`claude/dual-port`):** 128-bit packer (4-chunk),
      core/wrapper/contract widened, default-OFF & proven bit-identical (FIFO-packer TB 423
      checks + integration TB 26,006 checks incl. 25,910-cycle co-sim vs main). Full build
      routes & meets timing (WNS +0.646, 0 failing endpoints, no congestion; LUTRAM 368→933).
      `blobs/BOOT.bin` rebuilt. **Remaining: run the on-hardware bandwidth measurement**
      (debug mode + `set_channels 0xFF` → ~150-word packets; confirm PS→UDP sustains ~18 MB/s).
- [~] **Phase 2 — real second-port capture + independent cable detection.** Add the two
      `IBUFDS` + phase selectors and `phase2`/`phase3`; extend `auto_cable_detect` / `net.py`
      INTAN-pattern sweep to run **per port** (different cable lengths → different optimal phase).
      **PL/firmware/host DONE 2026-06-15 (`claude/dual-port`):** 2nd LVDS buffer instance +
      `intan_spi_b` interface + external `spi_lvds_1` port; port-B pins on **bank 35** (CS=F19/F20,
      SCLK=J20/H20, COPI=H15/G15, cipo2=L14/L15, cipo3=K16/J16 — verified placed in the routed
      checkpoint). Build routes + meets timing (WNS +0.133, 0 failing). Per-port phase via
      `set_phase <p0> <p1> [p2 p3]` / `CMD_SET_PHASE_B`; phases shown in the core-1 status snapshot.
      `blobs/BOOT.bin` rebuilt. **Remaining: (1) on-hardware bring-up** — plug a 2nd analog
      headstage into port B, sweep `set_phase ... p2 p3` for the INTAN pattern, confirm real
      neural on port B; **(2) automate per-port `auto_cable_detect`** (host-only, best done with
      the board). COPI's bank-35 IO_L19 (H15/G15) **schematic-verified 2026-06-15** — all
      port-B pins confirmed.
- [ ] **Phase 3 — plugin multi-input (acq-board model).** One `DataStream`, channels grouped by
      port with prefixes (`A_CH1…` / `B_CH1…`, per-port AUX), per-port chip detection in the
      editor. Mirrors `acquisition-board` `DeviceThread`/`Headstage` (single stream, prefixed
      headstage groups, `setFirstChannel` offsets).
- [ ] **Future — independent per-port commands.** Split command generation (or a second light
      FSM) so one port can run SPI + analog aux while the other runs the I²C-repurpose **digital
      IMU** (lab has one digital-IMU headstage + two analog). Pins already exist; design the
      Phase-1 register layout so this stays additive.

---

## Reference designs (OpenEphys / Intan open source)

References mined while scoping the above. Note OE's 3rd-gen path uses **liboni/ONI framing**
(a software protocol), *not* ONIX coax hardware — the 3D headstage still connects over the
standard Intan SPI Omnetics cable.

- [open-ephys/rhythm](https://github.com/open-ephys/rhythm) — Intan/OE **Rhythm FPGA** Verilog:
  fast-settle injection, looping **aux command banks** (template for "generalize COPI sequences"),
  DDR/MISO phase handling.
- [open-ephys/low-profile-headstage-64ch-3d](https://github.com/open-ephys/low-profile-headstage-64ch-3d)
  — OE 64ch **3D headstage** (RHD2164 + **BNO055**); KiCad schematic proves the dedicated SDA/SCL
  cable wiring (2nd MISO pair → I²C).
- [open-ephys-plugins/acquisition-board](https://github.com/open-ephys-plugins/acquisition-board)
  — OE GUI plugin; `AcqBoardONI.cpp` decodes the BNO frame;
  `rhythm-api/rhd2000registers.cpp::createCommandListTempSensor` builds the aux/accelerometer/
  temp/supply command bank.
- [open-ephys/commutator-controller](https://github.com/open-ephys/commutator-controller) — RP2040
  commutator firmware (JSON-`{turn}` follower; does *not* read the IMU).
- Intan **RHD2000 Rhythm** USB/FPGA reference (`RHD2000InterfaceXEM6010`, from intantech.com downloads).

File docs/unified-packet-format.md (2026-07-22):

# Unified single-port packet format (no-loss, no-MTU-framer)

Status: **design contract** for the `claude/unified-ports` (broadband + LFP) and the
follow-on `claude/unified-wavelet` branches, and the two matching `ephys-socket` branches.
This is the single source of truth — PL, firmware, `net.py`, and the Open Ephys plugin all
implement exactly this.

## Principles (from the CLAUDE.md hard rule)

1. **One UDP port** (default **0x6800 / 26624**) for ALL PL→host streams. The host demuxes by
   `stream_type` in the header. (Board-side this is TX-neutral; host-side we drain
   promiscuously so broadband is never blocked.)
2. **NO DATA LOSS.** Every packet fits **one standard datagram** (≤ 1472 B payload → no IP
   fragmentation, no jumbo, **no MTU framer**). We *specify* the data so it inherently fits;
   if a config wouldn't fit, we **reduce the spec**, never chunk-with-loss.
3. **Loss is provably zero**, not assumed: every packet carries a **per-stream monotonic
   sequence number**; the host flags any gap. Broadband's gap count must stay 0.

## Why one port (not one per stream)

The board could just as easily send each stream to its **own** UDP port — the PL builds
the complete wire packet (header + payload) in its output BRAM and the PS DMAs it straight
into a `PBUF_REF`, so a per-stream destination port costs the board nothing. The single
port is driven entirely by a **receiver-side** failure mode:

If a per-stream port has **no socket draining it** (that stream's consumer isn't running —
e.g. a viewer is closed), the receiving host's **OS kernel** — *because nothing is
listening* — replies **ICMP "port unreachable"** to every datagram sent there. At stream
rate that is a multi-kHz inbound flood, and the board's **fully-polled** lwIP stack
(`NO_SYS`, no interrupts) must receive and process every one of those ICMP replies. That
steals time from the 30 kHz acquisition loop (recv→transmit spikes to 40–60 µs against a
~33 µs budget) and drives catch-up bursts that exhaust the TX descriptors → **dropped
broadband**. Measured on the separate-LFP-port design: broadband-only pristine (~27 µs max,
0 over-budget, 0 drops); the LFP port left **undrained** → ~63 µs, ~250 over-budget, ~12
drops; that same port **drained** → identical to broadband-only. The firmware was never the
bottleneck — an unlistened UDP port was.

One port removes the failure mode **structurally**: there is only ever one socket, broadband
keeps it drained continuously, and an unconsumed stream (e.g. LFP) is simply demuxed and
ignored — it never lands on a dead port, so the host never emits ICMP and the board never
sees the storm. A host-side "always drain every stream port" rule also works, but it is
fragile (a GUI viewer can be closed mid-run); the single port makes it impossible to get
wrong. This is why principle 1 is one port + a `stream_type` tag, not a port per stream.

## Common header — 8 × 32-bit little-endian words (32 bytes), identical for every stream

| word | name | contents |
|---|---|---|
| 0 | `MAGIC` | `0xCAFEBABE` (all PL packets) |
| 1 | `TYPE_VER` | `[7:0]` stream_type · `[15:8]` version (=1) · `[31:16]` flags |
| 2 | `TS_LO` | 64-bit master timestamp, low word |
| 3 | `TS_HI` | 64-bit master timestamp, high word |
| 4 | `SEQ` | per-stream packet sequence, +1 each packet of that stream (wraps 32-bit) |
| 5 | `AUX0` | stream-specific (below) |
| 6 | `AUX1` | stream-specific (below) |
| 7 | `RSVD` | 0 (reserved; candidate for a future CRC32 of the packet) |

`stream_type`: **1 = BROADBAND, 2 = LFP, 3 = WAVELET.**

The host demuxes on `TYPE_VER[7:0]`. **Per-stream `SEQ` continuity = the loss check.** Keep
each stream's `SEQ` independent so broadband's integrity is unaffected by the others.

## Per-stream payloads

### BROADBAND (type 1) — unchanged content, re-framed
- `AUX0` = `channel_enable[7:0]` · `num_data_words[23:8]`
- `AUX1` = digital-in / metadata (preserve today's fields)
- Payload = the existing per-packet fields that don't fit the header (the 8 external-ADC
  values, any remaining metadata) **followed by** the data words. **Map ALL of today's
  10-word-header content into the new header + a small broadband sub-block — lose nothing.**
- Already ≤ 1 datagram (≤140 data words + header ≈ 600 B). Fits trivially.

**As implemented (claude/unified-ports):** the broadband frame is the 8-word common
header **+ a 6-word broadband sub-block = 14 header words** ahead of the data (the PL
writes these as 7 × 64-bit FIFO header writes). Word map (32-bit LE):

| word | contents |
|---|---|
| 0 | `MAGIC` = 0xCAFEBABE |
| 1 | `TYPE_VER` = 1 \| version<<8 \| flags<<16 |
| 2 / 3 | 64-bit master timestamp |
| 4 | `SEQ` (broadband per-stream, +1/packet; resets to 0 on START) |
| 5 | `AUX0` = `channel_enable[7:0]` \| `num_data_words[23:8]` |
| 6 | `AUX1` = `digital_in[7:0]` \| `aux_flags[15:8]` \| `echo_sweep[31:16]` (this packet's slot-0/accel command; its reply is data word 34) |
| 7 | `RSVD` = 0 |
| 8 | sub-block: prev-packet slot-1 (fs) \| slot-2 (inject) aux echoes = `{echo_inject[31:16], echo_fs[15:0]}` (replies land at data words 0/1) |
| 9..12 | sub-block: the 8 external-ADC breadcrumbs (currently 0) |
| 13 | sub-block: reserved (0) |
| 14.. | DATA words — **byte-identical** to the legacy format |

Verified in `programmable_logic/sim/dualport_dropout_tb.sv`: the data words still match
the legacy sine reference EXACTLY (content preserved) and SEQ/timestamp advance by 1 per
packet (the loss check). Max packet = 14 + 140 = 154 words = 616 B (≤ 1 datagram).

### LFP (type 2)
- `AUX0` = `lane_mask[7:0]` · `decim_R[15:8]` · `num_taps[23:16]` · `overrun[24]`
- `AUX1` = `num_samples`
- Payload = the decimated samples (int16, as today). One frame ≤ 1 datagram. Fits.

**As implemented (claude/unified-ports):** the LFP frame is exactly the 8-word common
header (no sub-block) then the decimated samples. `num_samples` = `popcount(lane_mask)·32`
(`lane_mask` mirrors the broadband `channel_enable`). The PL builds the whole frame
(header + samples) in its output BRAM; the PS DMAs it and sends it on UDP 0x6800 with
stream_type=2. Verified in `programmable_logic/sim/lfp_dsp_block_tb.sv`.

### WAVELET (type 3) — one octave per packet, rate-aligned
- **One packet = one octave.** `AUX0` = `octave[3:0]` · `n_octaves[7:4]` · `n_voices[11:8]`
  · `overrun[24]`. `AUX1` = `n_channels[7:0]` · `lane_start[23:8]`.
- Payload = `n_channels × n_voices` complex coefficients (re,im as int32 each) for **this
  octave only**, lane-major then voice-minor:
  `[(ch0,v0.re),(ch0,v0.im),(ch0,v1.re),(ch0,v1.im)...,(ch1,v0.re)...]`.
- **Rate-aligned emission:** emit octave *o*'s packet **only on the frames where it updates**
  (the à trous engine advances octave *o* when `fcount mod 2^o == 0` — the work-spread
  scheduler already computes this flag). So octave 0 streams at 3 kHz, octave 7 at ~23 Hz —
  **no redundant re-sending of slow bands** (≈4× less traffic than sending all octaves every
  frame). The host holds each octave's last value between its updates (the truthful
  representation of a multirate scalogram).
- **Fits one datagram by construction (no MTU framer):** `32 + n_channels·n_voices·8 ≤ 1472`
  ⇒ `n_channels·n_voices ≤ 180`. The monitored channel count is a **spec we bound** (e.g.
  ≤ 40 channels at V=4) so a one-octave packet always fits. Want more channels than fit?
  **Reduce the channel count** (the no-loss rule) — do not split/fragment. (Full 256-ch
  resolution is the future DDR/soft-core path, not this UDP monitor.)

## Host (net.py + Open Ephys)

- **One socket, port 0x6800, promiscuous drain:** a tight `recvfrom → ring` loop that never
  blocks on processing; demux + per-stream handling happen downstream. Big `SO_RCVBUF`.
- Demux by `TYPE_VER[7:0]`; verify per-stream `SEQ` continuity (the loss check).
- Wavelet: place each packet's `(octave, lane_start..+n_channels)` block into the surface;
  hold each octave between its rate-aligned updates.

## Branch plan

1. `claude/unified-ports` (off `main`): broadband + LFP on port 0x6800 with this header. PL
   (both packet builders) + firmware (single send path/port) + `net.py` (one socket, demux)
   + sim. **No wavelet.**
2. `claude/unified-wavelet` (off `unified-ports`): port the v2 wavelet engine on top, add the
   octave-split rate-aligned WAVELET packets.
3. `ephys-socket` branch 1: consume the unified port (broadband + LFP demux).
4. `ephys-socket` branch 2 (off branch 1): add the WAVELET scalogram consumer.

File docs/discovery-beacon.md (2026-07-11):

# Device discovery beacon

Once fully initialized, the board **broadcasts** a small identity datagram ~1 Hz.
A client uses it to discover the board's IP, know the board is up, and stay fully
passive during the board's fragile boot window (no packets to the board until it
has announced itself — the clean way to avoid the early-connect RX wedge).

## Transport
- **Subnet-directed broadcast** to `<subnet>.255` (e.g. `192.168.18.255`), UDP
  **port 0x6880 / 26752** (`BEACON_PORT`).
- Sent every ~1 s from `network_maintenance_loop` while the link is up, once the
  board has finished init (so hearing it == "ready to connect").
- Broadcast on purpose: needs no IGMP, and a host with no listener on 0x6880 will
  **not** send an ICMP port-unreachable (hosts don't ICMP-error broadcasts), so an
  idle beacon never storms anyone.

## Wire format — `device_beacon_t` (28 bytes, little-endian, naturally aligned)

| Off | Type | Field | Notes |
|-----|---|---|---|
| 0 | u32 | `magic` | `0x4B4C4231` (`BEACON_MAGIC`) |
| 4 | u32 | `version` | `1` (`BEACON_VERSION`) |
| 8 | u32/4B | `ip` | board IPv4, **network byte order** (== datagram source) |
| 12  | u16 | `tcp_port`  | control port (0x6900) |
| 14  | u16 | `udp_port`  | unified data port (0x6800) |
| 16  | u32 | `fw_version`| `maj<<24 | min<<16 | patch<<8 | build` |
| 20  | u8[6] | `mac` | board MAC = unique device id |
| 26  | u16 | `reserved`  | 0 |

Defined in `firmware/include/main.h` (`device_beacon_t`, guarded by a
`_Static_assert` on the 28-byte size), built in `firmware/src-core0/network.c`
(`beacon_send`). **Keep these three in sync:** firmware, `remote/net.py`
(`_parse_beacon`, format `'<II4sHHI6sH'`), and the ephys-socket plugin.

## Client pattern
1. Bind UDP 0x6880/26752 (`INADDR_ANY`, `SO_REUSEADDR`), listen.
2. On a datagram: check `magic`, take the **source address** as the board IP
   (authoritative), read ports / fw / mac from the payload.
3. If several boards answer, list them by MAC and let the user pick.
4. Only then open the TCP control connection (bounded, paced retry — see
   `connect_with_retry` in net.py / the ephys-socket TODO). If no beacon arrives
   within a timeout, fall back to a configured IP (for older firmware).

net.py implements all of this (`discover_board`, and the `__main__` gate that
auto-fills `ZYNQ_IP`). ephys-socket should mirror it (phase 2).

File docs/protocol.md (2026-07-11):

# Command & packet structure

The board exposes two network endpoints once its Ethernet link is up:

| Endpoint | Port | Direction | Purpose |
|---|---|---|---|
| **TCP control** | 0x6900 | host → board (with acks) | commands (start/stop, config, registers) |
| **UDP data** | 0x6800 | board → host | the acquisition stream |

Default board IP is `192.168.18.10` (put your host on the same `/24`).

`remote/net.py` and `firmware/include/main.h` are the **authoritative** sources for the
exact IDs, bit layouts, and offsets — this document is the readable summary. The firmware,
`net.py`, and the `ephys-socket` plugin are the **three consumers of the same contract**;
changing it means changing all three.

## TCP control commands

Every command is a fixed **20-byte** little-endian frame:

```
uint32  magic    = 0xDEADBEEF      (CMD_MAGIC; note this is the COMMAND magic, not the packet magic)
uint32  cmd_id
uint32  ack_id                     (echoed back in the ack so the host can match responses)
uint32  param1
uint32  param2
```

Most commands reply with a small ack; `GET_STATUS`, `READ_REGISTER`, etc. reply with data.

| cmd_id | Name | params | Notes |
|---:|---|---|---|
| `0x01` | START | — | begin streaming |
| `0x02` | STOP | — | stop streaming |
| `0x03` | RESET_TIMESTAMP | — | zero the packet timestamp |
| `0x10` | SET_LOOP_COUNT | p1 = count | 0 = free-run; N = stream N packets then stop |
| `0x11` | SET_PHASE | p1 = phase0, p2 = phase1 | **port A** CIPO0/CIPO1 sampling phase (cable length) |
| `0x14` | SET_PHASE_B | p1 = phase2, p2 = phase3 | **port B** (2nd cable) CIPO0/CIPO1 phase |
| `0x12` | SET_DEBUG_MODE | p1 = 0/1 | synthetic sine instead of real CIPO (no chip needed) |
| `0x13` | SET_CHANNEL_ENABLE | p1 = mask | 8-bit stream mask (e.g. `0xFF` = all 8 streams / 256 ch) |
| `0x20` | LOAD_CONVERT | — | load the per-sample CONVERT command sequence |
| `0x21` | LOAD_INIT | — | load the RHD2000 init/config sequence |
| `0x22` | LOAD_CABLE_TEST | — | load the cable/phase test sequence |
| `0x30` | FULL_CABLE_TEST | — | run the full phase sweep |
| `0x40` | GET_STATUS | — | returns the `status_response_t` struct (see below) |
| `0x41` | DUMP_BRAM | p1 = word, p2 = count | debug: dump BRAM words to the serial console |
| `0x50` | SET_UDP_DEST | p1 = ip, p2 = port | set the UDP stream destination |
| `0x60` | PING | — | liveness check |
| `0x70` | AUX_WRITE_WORD | p1 = slot \| bank<<8 \| is_len<<16; p2 = addr<<16 \| data | write an aux command-bank word |
| `0x71` | AUX_BANK_SELECT | p1 = slot; p2 = bank | select the active aux bank for a slot |
| `0x72` | AUX_SEQ_EN | p1 = 0/1 | enable the aux command sequencer |
| `0x73` | READ_REGISTER | p1 = reg | → 4-byte `{cipo1, cipo0}` response |
| `0x74` | WRITE_REGISTER | p1 = reg, p2 = value | → 4-byte echo |
| `0x75` | SET_FAST_SETTLE | p1 = amp cfg, p2 = dsp cfg | `sw \| gpio_en<<1 \| pin<<4` per field |
| `0x76` | SET_DIGOUT | p1 = sw \| gpio_en<<1 \| pin<<4; p2 = reg3 static byte | digital-out control |
| `0x80` | LFP_ENABLE | p1 = 0/1 | enable the LFP/DSP engine + its UDP stream |
| `0x81` | LFP_SET_PARAMS | p1 = decim_R, p2 = num_taps | decimation factor + active FIR length |
| `0x82` | LFP_SET_CHANNELS | *(deprecated)* | **DEPRECATED** — the LFP lane mask now mirrors the broadband `channel_enable` mask (use `SET_CHANNEL_ENABLE` `0x13`); firmware accepts-and-ignores |
| `0x83` | LFP_WRITE_COEF | p1 = [0] clear-ptr-first, p2 = 18-bit signed coef | upload one Q1.17 tap |

Configure LFP while disabled (params → coefficients via repeated `0x83`, the first with the
clear bit), then `LFP_ENABLE`. The **lane mask = the broadband `channel_enable` mask** (single
source of truth) — pick which streams to LFP-filter with `SET_CHANNEL_ENABLE` (`0x13`); the
LFP filters exactly the broadband-enabled lanes. (See `remote/net.py` `configure_lfp()`
+ `design_cic_comp_fir()` / `design_lfp_lowpass()`.)

(See `remote/net.py` for the exact per-command parameter packing and the interactive
command names like `start`, `set_channels`, `auto_cable_detect`, `verify_sine`.)

## UDP data packet (port 0x6800)

Each UDP datagram is **one 30 kHz sample frame**: `10` header words + `N` data words, all
32-bit little-endian. The 64-bit timestamp (header words 2–3) increments once per datagram.

**Header (10 words / 40 bytes):**

| words | field | notes |
|---:|---|---|
| 0–1 | magic `0xCAFEBABE_DEADBEEF` | word0 = `0xDEADBEEF`, word1 = `0xCAFEBABE` |
| 2–3 | 64-bit timestamp | increments once per packet (per sample frame) |
| 4–5 | digital-in (8 bits) + metadata | |
| 6–9 | 8 × 16-bit external ADC values | |

### Which channels get sampled — the channel-enable mask

`SET_CHANNEL_ENABLE` (`0x13`, param1) is an **8-bit mask selecting which of 8 streams** are
sent. Each set bit adds one stream of 32 amplifier channels; `0xFF` = all 8 = **256 channels**.
The bit order is **also the order the streams appear in every packet**:

| bit | stream | cable/port | CIPO line | phase |
|----:|---|---|---|---|
| 0 | `A_CIPO0_REG` | A (cable 1) | CIPO0 | regular |
| 1 | `A_CIPO0_DDR` | A | CIPO0 | DDR (2nd interleaved chip) |
| 2 | `A_CIPO1_REG` | A | CIPO1 | regular |
| 3 | `A_CIPO1_DDR` | A | CIPO1 | DDR |
| 4 | `B_CIPO0_REG` | B (cable 2) | CIPO0 | regular |
| 5 | `B_CIPO0_DDR` | B | CIPO0 | DDR |
| 6 | `B_CIPO1_REG` | B | CIPO1 | regular |
| 7 | `B_CIPO1_DDR` | B | CIPO1 | DDR |

Each stream = one RHD2000 chip's **32 amplifier channels** (the DDR streams are the second
chip interleaved on the same CIPO line via double-data-rate). 8 × 32 = 256.

### Data words — layout (this is what a receiver/plugin must de-interleave)

Each enabled stream contributes **35 16-bit samples per frame** (the 35 COPI commands of the
acquisition loop), packed **two samples per 32-bit word, low half first**:

```
data_word[i] = (sample[2*i+1] << 16) | sample[2*i]
```

Total = `35 × popcount(mask)` 16-bit samples = `ceil(that / 2)` 32-bit words. So the packet is
**28 words (min, 1 stream) … 150 words / 600 bytes (max, `0xFF`, 8 streams)**.

The samples are **cycle-major** — the outer loop is the 35 cycles, the inner loop is the
enabled streams in **ascending bit order**:

```
flat_index = 0
for cycle in 0..34:                      # 35 COPI commands
    for stream in enabled_streams:       # ascending mask bit
        sample[cycle][stream] = data_sample[flat_index];  flat_index += 1
```
So `sample(cycle, stream)` is at flat index `cycle * num_enabled + (rank of stream among enabled)`.

**Mapping cycle → amplifier channel.** Because of the 2-command SPI readback pipeline, a
`CONVERT(ch)` result lands two cycles later, so **amplifier channel `ch` (0–31) is at
`cycle = ch + 2`**. Cycles 0, 1, and 34 carry pipeline/aux readback (register reads, etc.),
**not** amplifier data — a displaying plugin should take cycles 2–33 as channels 0–31.

**Samples are offset binary** (mid-scale `0x8000` = 0 µV) — subtract `0x8000` for signed. This
layout is identical in debug mode (`SET_DEBUG_MODE`), which fills the streams with synthetic
sinewaves so a plugin can be tested with no chip attached.

**Reference parser:** `net.py` `unpack_data_segments()` (flatten words → 16-bit samples) +
`expected_debug_segments()` (the cycle×stream order) + `calculate_packet_size()` (size from
mask). The host/plugin **must** compute the expected size from the mask and check it — a size
mismatch is the classic dual-port "dropout" symptom; keep the plugin's size calc in lockstep.

## LFP UDP stream (port 5001) — the decimated band, a *separate* product

When the LFP/DSP engine is enabled, the board emits a second, independent UDP stream on
**port 5001** (broadband on 0x6800 is untouched). One datagram per decimation frame
(broadband rate ÷ effective decimation, e.g. 30 kHz ÷ 10 = 3 kHz).

**The PL builds the whole wire packet** (6-word header + samples) in the LFP output BRAM
(`0x84000000`) — just like `data_generator_core.sv` builds the 10-word broadband header in the
capture BRAM. The PS then **CDMAs the complete frame straight into a pbuf and sends it**
(`pl_dma_read_addr` → non-cacheable LFP staging → `udp_sendto` a `PBUF_REF`): no PS-side header
math and no `Xil_In32` sample loop (enforced by `scripts/check_dma.sh`). All 32-bit
little-endian:

| words | field | notes |
|---:|---|---|
| 0–1 | magic `0xCAFEBABE_1F1FBEEF` | word0 = `0x1F1FBEEF`, word1 = `0xCAFEBABE` (distinct from broadband) |
| 2–3 | 64-bit master **timestamp** | the master count of the **newest broadband sample in this output's decimation window** — the most recent broadband packet clocked into the (FIR) filter bank for this output. For frame `m` at total decimation `R` it is broadband packet `R·m + (R−1)` (R=10 → `10m+9`); the *same* counter the broadband header stamps (word 1). Causal, monotonic, `R` apart — an **absolute master timestamp**, not a frame index. NB: this is the newest *input* sample, not the instant the LFP value represents — subtract the filter group delay to align with broadband *content*. |
| 4 | `[7:0]` lane_mask · `[15:8]` decim_R · `[23:16]` num_taps · `[31:24]` overrun | self-describing config; `lane_mask` = the broadband `channel_enable` mask |
| 5 | 32-bit frame sequence number | PL-maintained (++ per emitted frame); LFP-stream drop detection |
| 6… | payload: per enabled lane, 32 decimated samples, **offset binary** 16-bit, 2 per word | `popcount(lane_mask) × 32` samples = `popcount × 16` words |

**Lane mask = broadband mask.** The LFP `lane_mask` is driven from the broadband
`channel_enable` mask in the PL (single source of truth) — the LFP filters exactly the
broadband-enabled lanes. **Samples are offset binary** (mid-scale `0x8000` = 0 µV), same as
broadband — subtract `0x8000` for signed. Lanes appear in ascending order; within each, the 32
amplifier channels in order. The host knows the frame size from `lane_mask`. Reference
receiver: `net.py` `receive_lfp()`.

## Register map (the source of truth is `firmware/include/main.h`)

| Region | Base | Notes |
|---|---|---|
| AXI-Lite control regs | `0x40000000` | 28 control regs (PS→PL): 0..21 legacy, 22..24 aux, **25..27 LFP** (cfg/coef/strobe) |
| AXI-Lite status regs | `0x40000000 + 28*4` | status regs (PL→PS): write pointer, fifo count, aux, **13 = LFP wr-ptr/overrun** (base = `PL_N_CTRL_REGS*4`) |
| Capture BRAM | `0x80000000` | 16384 × 32-bit words (64 KB) |
| **LFP output BRAM** | `0x84000000` | 16384 × 32-bit ring; PL builds the **whole wire packet** here (6-word header + samples 2×16-bit/word). In `axi_cdma_0/Data` space so the PS CDMAs each frame straight into a pbuf. |

`CTRL_REG_2` packs the four cable phases: `[3:0]` phase0 (A/cipo0), `[7:4]` phase1 (A/cipo1),
`[19:16]` phase2 (B/cipo0), `[23:20]` phase3 (B/cipo1).

### `get_status` response (`status_response_t`)
A packed **160-byte** little-endian struct returned by `GET_STATUS`. `main.h` is the
source of truth for the field layout; `net.py` `get_status()` mirrors the unpacking, and a
firmware `_Static_assert(sizeof(status_response_t) == 160)` keeps the two in sync. Contents,
in order:

- **version / IDs** — firmware version, board/build IDs.
- **PL hardware status** — 64-bit timestamp, BRAM write pointer, FIFO count, PL flags.
- **PS counters** — packets sent, error counters, PS flags.
- **current config** — `loop_count`, `phase0`/`phase1`, `channel_enable` mask, `debug_mode`.
- **UDP info** — destination IP/port, packet format, bytes sent.
- **aux-sequencer status** — `aux_read_result` (last injected command's `{cipo1, cipo0}`
  response), `aux_bank_active`, `aux_flags` (bit0 seq_en, bit1 fast-settle active, bit2
  digout, bit3 dsp, bit4 inject-ack), per-slot `aux_idx[3]`.
- **performance instrumentation** — per-packet CDMA and receive→transmit times as raw
  global-timer ticks (`dma_ticks_last/max`, `loop_ticks_last/max`), `dma_errors`, and
  `timer_hz` so the host converts ticks→µs (kept as ticks on the wire; converted only when
  printed).
- **`aux_ctrl` (`uint32`)** — `CTRL_REG_22` read back: the live fast-settle / DSP-reset /
  digout configuration (each as software-on / gpio-enable / gpio-pin-select fields), plus
  `seq_en`, active bank, and the static Reg-3 byte. Per the "get_status reports everything
  configurable" rule (CLAUDE.md).
- **`rhd_reg[22]` (`uint8` ×22)** — **RHD chip register mirror**: the firmware's view of the
  commanded state of RHD2000 registers 0..21. Seeded from the initialization sequence at
  boot (`pl_rhd_shadow_init`) and updated whenever a `WRITE_REGISTER` succeeds
  (`pl_write_rhd_register`). This is the *commanded* state, not a chip read-back — it lets a
  host/plugin recover the configured bandwidth, DSP cutoff, amplifier power-up mask, etc.
  without re-reading the chip. Registers 0 and 3 are owned by the PL override layer (amp
  fast-settle D5 and digout/temp); their *live* values are reported via `aux_ctrl`/
  `aux_flags`, so the mirror leaves those two as the static base.

  Useful registers in the mirror (see the RHD2000 datasheet for the full map):

  | reg | meaning |
  |-----|---------|
  | 0 | ADC config + amp fast-settle (bit D5 — overridden live) |
  | 3 | digital-out / temp-sensor (overridden live) |
  | 4 | DSP high-pass: enable (bit 4) + cutoff code (bits 3:0) |
  | 8, 10 | RH1/RH2 DACs — upper-bandwidth setting |
  | 12, 13 | RL DACs — lower-bandwidth setting |
  | 14–21 | per-channel amplifier power-up (8 bits each → 64 channels) |

- **LFP engine config + status (12 bytes)** — `lfp_enable`, `lfp_lane_mask`, `lfp_decim_R`,
  `lfp_num_taps`, `lfp_packets_sent` (UDP frames emitted), and `lfp_overrun` (sticky
  compute-overrun from `STATUS_REG_13`). `lfp_lane_mask` is reported as the **broadband
  `channel_enable` mask** (the single source of truth — the PL drives the LFP lane mask from
  `channel_enable_reg`), so the host can read back the full LFP configuration per the "report
  everything configurable" rule.

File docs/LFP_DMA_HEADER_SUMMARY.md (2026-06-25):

# LFP PL→PS DMA-correct path (PL-built header + mask mirror)

Branch: `claude/lfp-3khz`. Makes the LFP (Tier-1) PL→PS path fully DMA-correct: the **PL
builds the complete LFP wire packet** (header + samples) in the LFP output BRAM, and the PS
just **CDMAs it straight into a pbuf and sends it** — no `Xil_In32` sample loop, no PS-side
header math. The **LFP lane mask mirrors the broadband channel-enable mask**.

## PL-built LFP packet (in `lfp_dsp_block.sv`)

LFP output BRAM (`0x84000000`) layout, per frame = one complete wire packet:
`[6 header words | decimated sample words]`.

Header (6 words, little-endian on the wire):

| word | field | value |
|-----:|---|---|
| 0 | magic low  | `0x1F1FBEEF` |
| 1 | magic high | `0xCAFEBABE` |
| 2 | timestamp low  | `ts[31:0]` |
| 3 | timestamp high | `ts[63:32]` |
| 4 | cfg | `lane_mask | (decim_R<<8) | (num_taps<<16) | (overrun<<24)` |
| 5 | seq | PL-maintained LFP frame counter, ++ per emitted frame |

A small header-write micro-sequence in `lfp_dsp_block.sv`, triggered by the engine's
`frame_tick` (= the decimation tick / `start_pass`, exposed from `lfp_halfband.sv` and
`lfp_fir_decimator.sv`), writes the 6 header words at the frame base, advancing the BRAM write
pointer; the decimated samples then pack (signed → offset-binary, 2×16-bit/word) immediately
after. `frame_tick` leads the frame's first `out_valid` by ~`num_taps` clk (≫ 6), so header
and sample writes never race. `lfp_wr_addr` (PS read pointer, STATUS_REG_13) only advances past
a full `[header|samples]` frame, so the PS never reads a torn frame.

## Timestamp semantics

The decimating filters are just FIR: when one emits an output there is exactly one real,
already-acquired broadband sample that is the **newest input in that output's support window**,
and the stamp is that sample's master count.

**`ts` = the master count of the newest broadband sample in this output's decimation window**
— i.e. the most recent broadband packet clocked into the filter bank for this output, the
*same* counter the broadband header stamps (word 1). For frame `m` at total decimation `R` it
is broadband packet `R·m + (R−1)`. Causal, monotonic, `R` apart; an absolute master timestamp,
not a frame index.

Accounting through the CIC(/5)→halfband(/2)=/10 cascade:
- CIC emits on every 5th broadband `packet_tick` → CIC output `k` ↔ newest broadband packet `5k+4`.
- halfband emits on every 2nd CIC output → halfband output `m` ↔ CIC output `2m+1` ↔ newest
  broadband packet `5·(2m+1)+4 = 10m+9`.

Implementation: `data_generator_core.sv` exposes the live master `timestamp` as
`dsp_master_timestamp` (it has already incremented to "just-finished packet + 1" on the edge
`dsp_packet_tick` rises, so the finished packet's count is `dsp_master_timestamp − 1`).
`lfp_dsp_block` updates `ts_ingest` to that on **every** `dsp_packet_tick`, and snapshots it
into the header on `frame_tick` (the halfband decimation tick). The cascade latency (CIC comb
pass + glue replay, a few hundred clk) is far less than one ~2800-clk broadband packet, so no
new `packet_tick` arrives in between and the snapshot is exactly `10m+9`. (A frame-behind slip
under load would set `compute_overrun` → header word 4 bit 24.)

**This marks the newest *input* sample, not the instant the LFP value represents** — a
linear-phase anti-alias filter's output is centered earlier by the chain's group delay (a
fixed, known number of broadband samples). Subtract the group delay to align an LFP sample
with the broadband stream's *content*; use the stamp directly to know which input data has
been folded in. No RTL change for correctness — the stamp is the causal window-edge count by
design.

## LFP lane mask = broadband mask (single source of truth)

`data_generator_core.sv` exposes `channel_enable_reg` as `dsp_channel_enable`; `lfp_dsp_block`
drives the engine `lane_mask` from it (not from `lfp_cfg[15:8]`). The LFP filters exactly the
broadband-enabled lanes — pick streams with `set_channels` (broadband mask). `lfp_cfg[15:8]`
and `CMD_LFP_SET_CHANNELS` are deprecated (firmware accepts-and-ignores; net.py drops the mask
arg). `get_status` reports `lfp_lane_mask = pl_get_current_channel_enable()`.

## BD change (`design_1_bd.tcl`)

Added `0x84000000` (`axi_bram_ctrl_1/S_AXI/Mem0`) into `axi_cdma_0/Data`, mirroring the
existing `0x80000000` capture-BRAM CDMA assignment (no `exclude_bd_addr_seg` for it).
`smartconnect_1` already routes the CDMA (SI) to `axi_bram_ctrl_1` (M02). The CDMA Data space
now holds `0x80000000`, `0x84000000`, and DDR (HP0).

## Firmware (`network.c`, `pl_dma.c`, `pl_control.c`)

- `pl_dma_read_addr(dst, src_addr, n)` — generalized CDMA read from an arbitrary BRAM source
  byte address (the LFP BRAM); `pl_dma_read_bram` now wraps it.
- A dedicated non-cacheable LFP staging buffer (`pl_dma_lfp_staging`, 1 MB-aligned) so the LFP
  CDMA + zero-copy pbuf never clobber the broadband staging buffer.
- `lfp_stream_service` rewritten: on a complete frame (PL write pointer vs read pointer), CDMA
  the whole `[header|samples]` frame from the LFP BRAM into the LFP staging buffer (split at
  the ring wrap), then `udp_sendto` a `PBUF_REF`. **The PS-side header construction
  (`lfp_pktbuf[0..5]`) and the `Xil_In32` sample loop are deleted.**
- `pl_lfp_set_config` drops the `lane_mask` param (writes 0 to `lfp_cfg[15:8]`, which the PL
  ignores). `CMD_LFP_SET_CHANNELS` accepts-and-ignores.
- `status_response_t` size unchanged (168 B) — `_Static_assert` unchanged.

## `check_dma` result

`bash scripts/check_dma.sh firmware` → **PASS** (6 exempt). The LFP `Xil_In32` loop is **gone**
(now CDMA). The remaining single-beat sites are annotated `// DMA-EXEMPT`: the magic/resync
2-word peeks (`main.c`), the `BRAM_READ_SINGLE` reference reader (`main.c`), and the `dump_bram`
debug single-beat reference reader (`pl_control.c`).

## Sim

All LFP TBs pass under xsim (Vivado 2025.1):
- `lfp_dsp_block_tb` — PASS (864 BRAM words: 16 frames × (6 header + 48 sample words);
  verifies the PL-built header, timestamp, seq, and the broadband-mask-driven lane mask).
- `lfp_halfband_tb`, `lfp_fir_decimator_tb`, `cic_decimator_tb`, `cic_chain_tb` — PASS
  (new `frame_tick` output, engines unchanged otherwise).
- `data_generator` aux/chirp/dualport-dropout TBs — PASS (new `dsp_master_timestamp` /
  `dsp_channel_enable` taps wired; dualport runner fixed to compile the LFP sources).

## Build (Vivado 2025.1, `xc7z020clg400-1`, fresh create → bitstream)

BD changed → full `create_vivado_project.tcl` → `build_bitstream.tcl`. `write_bitstream
completed successfully`; BD validated + synthesized with 0 errors (no critical warning mentions
any new LFP signal).

**Timing — all constraints met** (`design_1_wrapper_timing_summary_routed.rpt`):

| clock | freq | period | setup WNS | hold WHS | failing |
|---|-----:|---:|---:|---:|---:|
| clk_out1 (84 MHz data path) | 84.000 MHz | 11.905 ns | **+0.714 ns** | +0.022 ns | 0 |
| clk_out2 (AXI/GP) | 131.250 MHz | 7.619 ns | +0.814 ns | +0.050 ns | 0 |

Overall WNS +0.714 / TNS 0.000 / WHS +0.022, 0 failing endpoints (96289). The 84 MHz path stayed
positive (new header FSM / 64-bit timestamp latches / seq counter are registered and off the
critical path) — better than the ~0.45 ns the task flagged.

**Utilization** (`design_1_wrapper_utilization_placed.rpt`):

| resource | used | avail | % |
|---|-----:|---:|--:|
| Slice LUTs | 17029 | 53200 | 32.0 |
| Slice Registers | 33664 | 106400 | 31.6 |
| Block RAM Tile | 46.5 | 140 | 33.2 |
| DSPs | 1 | 220 | 0.45 |

BRAM unchanged by the header-in-PL change (the LFP output BRAM was already allocated); the BD
CDMA address add is routing-only.

## Firmware build (Vitis 2025.1, -O3, both cores)

Fresh `create_vitis_project.py` from the new `.xsa`. Platform + both cores all report
**`Build Finished successfully`** (0 errors, 0 warnings on the changed files). The
`_Static_assert(sizeof(status_response_t) == 168)` **passes** (main.c compiled clean at -O3;
struct size unchanged — `lfp_lane_mask` is still a `uint8_t`, only its source changed to the
broadband mask). ELFs: `klab-firmware.elf` (core 0, ~1.13 MB), `klab-firmware-core1.elf`
(core 1, ~0.30 MB).

## check_dma

`bash scripts/check_dma.sh firmware` → **PASS, exit 0** (0 violations, 6 exempt). The LFP
`Xil_In32` sample loop is gone (now CDMA); the 6 exempt sites are the magic/resync 2-word
peeks + the `BRAM_READ_SINGLE` reference reader (`main.c`) and the `dump_bram` debug
single-beat reader (`pl_control.c`), each annotated `// DMA-EXEMPT: <reason>`.

## Note on BOOT.bin

No new `blobs/BOOT.bin` is committed: this change is **HW-UNVALIDATED** (built + sim-verified
here, not run on a board). The existing committed `blobs/BOOT.bin` is left untouched. A test
image can be bootgen'd from the fresh bitstream + ELFs if needed; mark any such image
HW-UNVALIDATED.

## HW test steps (not run here — HW-UNVALIDATED)

1. Flash the fresh `BOOT.bin`, connect, send one `get_status` to prime (DDR-remanence guard).
2. `set_channels 0x05` (or any mask) → `lfp_config cic` → `lfp_on` → `start`.
3. `lfp_recv 200`: confirm magic, `lane_mask` == the broadband mask, `seq` monotonic, `ts`
   advancing by the decimation stride, and sample count == `popcount(mask)*32`.
4. `get_status`: `lfp_lane_mask` == broadband `channel_enable`; `lfp_overrun` == no.
5. Cross-check an LFP sample's `ts` against the broadband stream's timestamp for alignment.

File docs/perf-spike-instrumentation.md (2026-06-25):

# recv→transmit spike instrumentation (firmware v1.4)

Tooling to pinpoint the occasional `recv→transmit` spike (typical ~16 µs, sticky
max seen ~40 µs) on the core-0 fast loop, even at broadband-only. **Hypothesis:**
the spike lives inside `udp_sendto(...)` — the GEM TX path reaps a *variable*
number of completed TX descriptors via `xemacps_process_sent_bds` (a `while(1)`
loop), so the send time is bursty. This instrumentation *measures* that rather
than guessing: it splits the timed recv→transmit window, captures the worst
packet's breakdown, and builds a distribution.

All times are stored as raw 333.3 MHz global-timer **ticks** and converted to
microseconds host-side in `net.py print_status` (the "store the measurement,
derive the display" convention already used by `loop_ticks`/`dma_ticks`).

## What gets measured (in `process_packet_from_bram`, `main.c`)

The recv→transmit window (`loop_ticks`, the 33.3 µs-budget metric) is split:

```
loop_ticks  =  cdma  +  send  +  other
                │        │        └─ everything else: magic peek, pbuf_alloc/free,
                │        │           pointer update, instrumentation
                │        └─ udp_sendto()  ← suspected spike source
                └─ pl_dma_read_bram() (CDMA BRAM→DDR)
```

`send` is timed by a new `XTime` pair straddling the single `udp_sendto` call.

## New `get_status` fields ("Performance" section)

| Field | Meaning |
|---|---|
| `UDP send: last/max` | `send_ticks_last` / `send_ticks_max` — the `udp_sendto` time, isolated. **The new headline number.** |
| `Worst pkt #N: cdma=… send=… other=…` | Snapshot of the worst recv→transmit packet's breakdown, captured the instant a new `loop_ticks_max` is set. `N` = `packets_received_count` at that packet. Shows *what dominated* the worst case. `other` is clamped ≥0 (the three sub-timers are sampled at slightly different instants). |
| `Recv->transmit histogram` | 6 buckets by microseconds: `[<16, 16–25, 25–33, 33–50, 50–100, ≥100]`, counts + % of packets. Shape of the tail. |
| `Over budget (>=33 us): N` | `over_budget_count` — packets whose recv→transmit exceeded the 33.3 µs budget. Frequency of the spike. |

The existing `CDMA transfer last/max` and `Recv->transmit last/max` lines are
unchanged.

## How to read it — is the spike the send path?

1. `perf_reset` to clear sticky maxes + histogram + counts (starts a fresh window).
2. Stream for a while at the config of interest.
3. `get_status`.

**Confirms the hypothesis (spike = GEM TX reaping) if:**
- `send_max` ≫ `cdma_max`, **and**
- the worst-packet breakdown shows `send` dominating (`send` ≫ `cdma`, `other`),
  **and**
- the histogram has a tail (non-zero counts in the `33–50` / `50–100` buckets)
  while the bulk sits in `<16`.

That pattern means recv→transmit is fast almost always but the rare slow packet
is spent inside `udp_sendto` — i.e. the variable TX-BD reap. The fix would then
be in the GEM TX path (e.g. cap/offload the reap, or pace sends), not the CDMA.

**Refutes it if** the worst-packet breakdown shows `cdma` or `other` dominating,
or `send_max ≈ cdma_max` with no histogram tail — then look elsewhere (CDMA
contention on S_AXI_HP0, or the `other` bucket = pbuf/lwIP bookkeeping).

## Control / wire contract

- New command **`CMD_PERF_RESET = 0x91`** (firmware `network.c`, host `net.py`
  `perf_reset`). Clears the sticky maxes, the worst-case snapshot, the histogram,
  and `over_budget_count` — but **not** the per-sample `last` fields or the
  lifetime `dma_errors`. An explicit reset (rather than reset-on-START) keeps the
  measurement window under user control.
- `status_response_t` grew **168 → 220 bytes** (appended a 52-byte block: 7×u32
  then 6×u32 histogram). The `_Static_assert(sizeof(status_response_t)==220)` in
  `main.c`, `collect_status_data` in `network.c`, and `net.py get_status`
  (length check + `data[168:196]`/`data[196:220]` unpack) were updated together.
- Firmware version bumped to **v1.4**.

## Notes

- No RTL/BD change — firmware + `net.py` only. The PL is unchanged, so `BOOT.bin`
  reuses the existing timing-closed bitstream.
- `scripts/check_dma.sh firmware` still PASSes: the instrumentation adds only
  `XTime_GetTime` calls and arithmetic — no single-beat BRAM/staging reads.
- `dma_ticks_last` (and thus `worst_cdma_ticks`) is only meaningful on the default
  `BRAM_READ_DMA` path; the compile-time `BRAM_READ_SINGLE` fallback doesn't set it.

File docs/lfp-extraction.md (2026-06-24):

# LFP extraction (Tier-1 on-PL DSP engine)

How the board turns the 30 kHz broadband neural stream into a decimated **local field
potential (LFP)** band, streamed as an independent data product. Part 1 is the signal-
processing theory (with references); Part 2 is the as-built PL implementation.

Companion docs: [`lfp-dsp-engine-design.md`](lfp-dsp-engine-design.md) (design rationale /
decision log) and [`PHASE_A_SUMMARY.md`](PHASE_A_SUMMARY.md) (the 3 kHz build results). This
doc is the reference for *what the engine is and why*.

---

## Part 1 — Signal-processing theory

### 1.1 What the LFP is

The extracellular potential recorded by a neural electrode is conventionally split into a
high-frequency band — spikes / multi-unit activity (~300 Hz–7 kHz) — and a low-frequency
band, the **local field potential** (~0.5–300 Hz), which reflects summed synaptic and
transmembrane currents in the local population [1][2]. Many experiments (theta/gamma
oscillations, sharp-wave ripples ~150–250 Hz, phase-targeted stimulation) only need the LFP
band, so it is worth extracting it as a compact, lower-rate stream rather than shipping the
full 30 kHz broadband.

Extracting the LFP is a **sample-rate conversion** problem: low-pass filter to the band of
interest, then **decimate** (downsample) to a rate just above its Nyquist requirement. Here:
30 kHz broadband → **3 kHz LFP** (decimation factor **R = 10**; Nyquist 1.5 kHz, usable band
to ~1 kHz). The raw broadband stream is never altered — LFP is a *derived* product on a
separate wire (data-fidelity rule).

### 1.2 Decimation and aliasing

Downsampling by R keeps every R-th sample, which folds (aliases) every input component above
the new Nyquist `f_s,out/2` back into the baseband [3][5][7]. To avoid corrupting the band of
interest you **must** low-pass *before* discarding samples, attenuating everything that would
alias onto `[0, f_pass]`. Concretely, with `f_s,out = 3 kHz`, any input energy near
`k·3 kHz ± [0,1 kHz]` would land in the passband after ÷10, so the anti-alias filter must be
down by the target stop attenuation across those folding bands. The design target here is
**flat to ~1 kHz, ≥46 dB alias rejection into the 0–1 kHz passband**.

### 1.3 Why multistage (CIC + compensation), not one big FIR

A single-stage FIR sharp enough for a ÷10 anti-alias at 30 kHz needs ~130–200 taps, and a
**time-shared** engine serving 256 channels then needs a large per-channel delay line (the
dominant memory cost). The classic, far cheaper approach for large integer decimation is
**multistage** [4][5][6]: do most of the rate reduction in a **cascaded integrator–comb
(CIC)** stage (no multipliers, tiny state), then a short FIR at the lower rate.

**CIC decimator (Hogenauer, 1981) [4].** A CIC of order `N` and rate-change `R` (differential
delay `M`) is `N` cascaded integrators at the *input* rate, a ÷R downsampler, then `N`
cascaded combs at the *output* rate. Its transfer function is

```
H(z) = [ (1 - z^-RM) / (1 - z^-1) ]^N      → magnitude ≈ | sin(π R M f / f_s) / sin(π f / f_s) |^N
```

i.e. a `sinc^N` low-pass with nulls at multiples of `f_s/(RM)` (exactly the images that fold
on decimation). Key properties:

- **No multipliers, no coefficient memory, no long delay line** — only `N` integrator and `N`
  comb accumulators per channel. This is the ~5× memory saving over the single-stage FIR.
- **DC gain `(R·M)^N`**, removed by an arithmetic right-shift (here `≈ R^N`).
- **Passband droop**: the `sinc^N` shape sags toward the band edge — corrected downstream.
- **Register bit-growth**: the accumulators must be wide enough that *modular* two's-complement
  wraparound is exact: `ACC_W ≥ input_W + ⌈N·log2(R·M)⌉` [4]. The integrators may overflow/wrap;
  the comb differences recover the correct result modulo `2^ACC_W` as long as the true output
  fits.

**Compensation / half-band FIR.** A short FIR at the CIC output rate (a) **flattens the CIC
passband droop** (its target is ≈ `1/sinc^N` over the passband) and (b) provides the final
sharp transition + a ÷2 decimation [5][6][7]. A half-band design is a natural fit for the ÷2.

### 1.4 The shipped filter: CIC⁴(÷5) → droop-comp half-band(÷2) = ÷10

| stage | rate in → out | role |
|---|---|---|
| CIC, order N=4, R=5, M=1 | 30 kHz → 6 kHz | bulk anti-alias + ÷5, multiplier-free |
| comp-FIR / half-band, 43 taps | 6 kHz → 3 kHz | flatten CIC droop + sharp edge + ÷2 |

**Combined response (as quantized to Q1.17):** flat to **~1 kHz (≤0.01 dB)**, −3 dB ≈ 1.25 kHz,
−6 dB ≈ 1.30 kHz, **−32 dB at the 1.5 kHz Nyquist**, **−54 dB worst alias-into-passband** —
comfortably past the 46 dB target. CIC order 3 only reached −42 dB, hence order 4. DC gain is
restored to unity by the comp-FIR (the CIC's `R^N/2^GAIN_SHIFT = 625/1024 = 0.61` is cancelled
by the comp-FIR's design-time normalization).

The comp-FIR is designed on the host (`design_cic_comp_fir` in `remote/net.py`) by
**frequency sampling** [7] with the desired passband response set to `1/CIC-droop`, windowed
(Kaiser β=6.0 [9]), normalized to unity combined DC gain, and quantized to Q1.17. The host
owns the filter design; the PL is a fixed-point engine.

> **Group delay.** Linear-phase FIR + CIC give a fixed, documented group delay; it changed
> with the CIC chain vs the legacy single-stage FIR (recompute it for absolute LFP↔broadband
> alignment). A *phase-targeted* closed loop (e.g. theta-phase stim) wants a low-order IIR or
> a phase predictor instead — noted as a future module.

---

## Part 2 — PL implementation

### 2.1 Datapath

```
data_generator_core (84 MHz, acquisition FSM)
   │  per-amplifier-channel sample tap (offset-binary), 1 word/slot @ packet_tick (30 kHz)
   ▼  offset-binary → two's-complement signed (^0x8000)   [lfp_dsp_block.sv]
cic_decimator.sv      CIC^4, ÷5   (integrators @ 30 kHz, combs @ 6 kHz)   → 6 kHz
   ▼
cic_to_halfband.sv    glue / handoff
   ▼
lfp_halfband.sv       droop-comp half-band FIR, ÷2                         → 3 kHz
   ▼  signed → offset-binary (^0x8000) ; write LFP output ring
LFP output BRAM @ 0x84000000  (64 KB, 2nd axi_bram_ctrl)
   ▼  AXI CDMA (BRAM→DDR over HP0), reusing the broadband path
PS core 0  → UDP stream, port 5001 (one LFP frame per packet)
```

All of this is wired in **`lfp_dsp_block.sv`**, selected by the `USE_CIC` parameter
(default **1** = the CIC chain above; **0** = the single-stage FIR fallback, §2.5).

### 2.2 Time-shared architecture

One datapath serves **all 256 channels** (8 lanes × 32 amplifier slots). Every channel
advances together — exactly one new sample per 30 kHz `packet_tick` — so a single schedule
walks `(lane, slot)` and **per-channel state lives in BRAM**, not in replicated logic. The
budget is generous: ~2800 PL clocks per 30 kHz tick (and ~14 000 between the ÷5 comb passes).
A `compute_overrun` flag latches (and the late frame is dropped, never corrupted) if a pass
can't finish in its window.

### 2.3 CIC engine — `cic_decimator.sv`

- Parameters: `R=5, N_ORDER=4, M=1, ACC_W=32, GAIN_SHIFT=10, OUT_W=16`. The bit-growth check
  is `ACC_W ≥ 16 + ⌈4·log2(5)⌉ = 26`, so 32 is comfortable [4].
- **State packing:** a channel's `N` integrator accumulators (and `N` comb accumulators) are
  packed into one wide BRAM word at `address = channel`. Each channel is a clean single read →
  combinational `N`-stage cascade → single write-back (no per-stage RAM addressing, no
  read-latency hazards). Read addresses are *combinational*; writes are registered.
- **Schedule:** the INTEGRATE pass runs every tick (per channel: read packed integrators,
  cascade-add the input, write back); on the R-th tick the COMB pass runs after it (read the
  top integrator = decimated value + packed comb state, cascade-difference, write back, emit).
- **Packet snapshot:** the integrate pass reads `in_snap` — a per-`packet_tick` freeze of the
  arriving sample word — not the live `in_buf`. On real hardware the *next* packet's slots
  start arriving ~80 clk after `packet_tick`, mid-pass, and would otherwise corrupt late-lane
  reads. (This is a general rule for any multi-packet compute pass; see `CLAUDE.md`.)
- **Output:** the final comb value `>>> GAIN_SHIFT` (≈ unity DC after comp-FIR), saturated to
  `OUT_W`. Integers wrap modulo `ACC_W`; the comb differences recover the exact result [4].

### 2.4 Compensation half-band + coefficients

`cic_to_halfband.sv` hands the 6 kHz CIC output to **`lfp_halfband.sv`** (the 43-tap
droop-comp FIR, ÷2 → 3 kHz). The taps are **host-designed and uploaded** — the PL holds no
filter design:

- Host: `design_cic_comp_fir(num_taps=43, fc=1300, beta=6.0, R_cic=5, n_order=4,
  gain_shift=10)` in `remote/net.py` → Q1.17 signed taps. **Must match**
  `programmable_logic/sim/gen_cic_chain_vectors.py` bit-for-bit.
- Upload: the **indirect-window** pattern — write taps through `CTRL_REG_LFP_COEF` (reg 26,
  `[17:0]` Q1.17) with a `CTRL_REG_LFP_STROBE` (reg 27) toggle/clear, streamed over TCP
  (`CMD_LFP_WRITE_COEF`). Coefficients latch only while streaming is stopped.

### 2.5 Fallback — single-stage dual-MAC FIR (`USE_CIC=0`)

`lfp_fir_decimator.sv` is a time-shared **dual-MAC** decimating FIR (131-tap Kaiser, fc=1250,
direct ÷10). It is the BRAM-heavy fallback (delay lines push BRAM to ~70% vs ~33% for the CIC)
and is timing-closed; kept for comparison and as a known-good reference. The host uploads its
131 taps with `configure_lfp(datapath="fir")`.
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

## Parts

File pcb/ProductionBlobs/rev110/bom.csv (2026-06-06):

Designator | Footprint | Quantity | Value | LCSC Part #
C1, C10, C16, C18, C2, C23, C3, C4, C5, C6, C7, C8 | 1206 | 12 | 22uF 25V | C12891
C11, C13, C15, C17, C19, C20, C21, C22, C24, C25, C9 | 0402 | 11 | 100nF | C307331
C12, C14 | 0603 | 2 | 10uF 10V | C19702
D1 | 0603 | 1 | LED0 | C2286
D10 | 0603 | 1 | LED3 | C2286
D2 | 0603 | 1 | LED1 | C2286
D3 | 0603 | 1 | LED 5V | C2286
D4 | 0603 | 1 | LED 2V5 | C2286
D5 | 0603 | 1 | LED 3V3 | C2286
D6 | 0603 | 1 | RX | C2286
D7 | 0603 | 1 | TX | C2286
D8 | SOT-23 | 1 | BAT54C | C37704
D9 | 0603 | 1 | LED2 | C2286
FB1 | 0805 | 1 | FerriteBead | C85840
J8 | USB_C_Receptacle_GCT_USB4105-xx-A_16P_TopMnt_Horizontal | 1 | USB_C_Receptacle_USB2.0_16P | C5184243
JX1, JX2 | BergStak-100pos-plug-61083-101400 | 2 | ~ | C2764776
L2, L3 | 1210 | 2 | 1 uH | C47492669
Q1, Q2, Q3, Q4 | SOT-23 | 4 | BSS138 | C400505
R1, R16, R25, R26, R30, R5 | 0402 | 6 | 1k 1% | C11702
R10 | 0402 | 1 | 5.6k 1% | C25908
R11, R23, R8 | 0402 | 3 | 100k 1% | C25741
R12, R22, R27 | 0402 | 3 | 3.3k | C25890
R13, R15, R17, R18, R19, R20, R21, R24 | 0402 | 8 | 150 1% | C25082
R14, R6 | 0402 | 2 | 316k 1% | C4338094
R2 | 0402 | 1 | 100 1% | C25076
R28, R29 | 0402 | 2 | 5.1k | C25905
R3, R4 | 0402 | 2 | 27 | C413051
R7 | 0402 | 1 | 10k | C25744
R9 | 0402 | 1 | 453k 1% | C3025678
SW1, SW2 | SW_SPST_TS-1088-xR020 | 2 | SW_Push | C720477
SW3, SW4 | SW_SPDT_PCM12 | 2 | SW_SPDT | C221841
U1 | SOT-25-5_L3.0-W1.8-P0.95-LS3.0-BR | 1 | AP331A | C151034
U2, U4 | SOT-23-6 | 2 | TLV62569DDC | C398365
U3 | SSOP-16_3.9x4.9mm_P0.635mm | 1 | FT230XS | C69082
U5 | Texas_DRX_WSON-10_2.5x2.5mm_P0.5mm | 1 | DAC70502 | C880348
U6, U9 | VSSOP-8_2.3x2mm_P0.5mm | 2 | ADS7029 | C2669867

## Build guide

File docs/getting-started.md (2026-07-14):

# Getting up and running

How to assemble a board, get a bootable image onto it, and make the first connection.
For the command/packet details see [`protocol.md`](protocol.md); for build internals and
conventions see [`../CLAUDE.md`](../CLAUDE.md).

## 1. Hardware

- A **MicroZed** Zynq-7000 SOM (7Z020; the 7Z010 should also work) on the
  [carrier PCB](../pcb/KiCad-Project/) (manufactured at JLCPCB).
- An Intan RHD2000-style headstage on a 12-pin Omnetics cable.
- A microSD card, Ethernet, and a **USB-C** cable. On the carrier the USB-C connector
  supplies **both power and the serial debug console** (UART) — the board draws about
  **0.65 A at 5 V**, so any standard USB-C port/charger is plenty.

<p align="center">
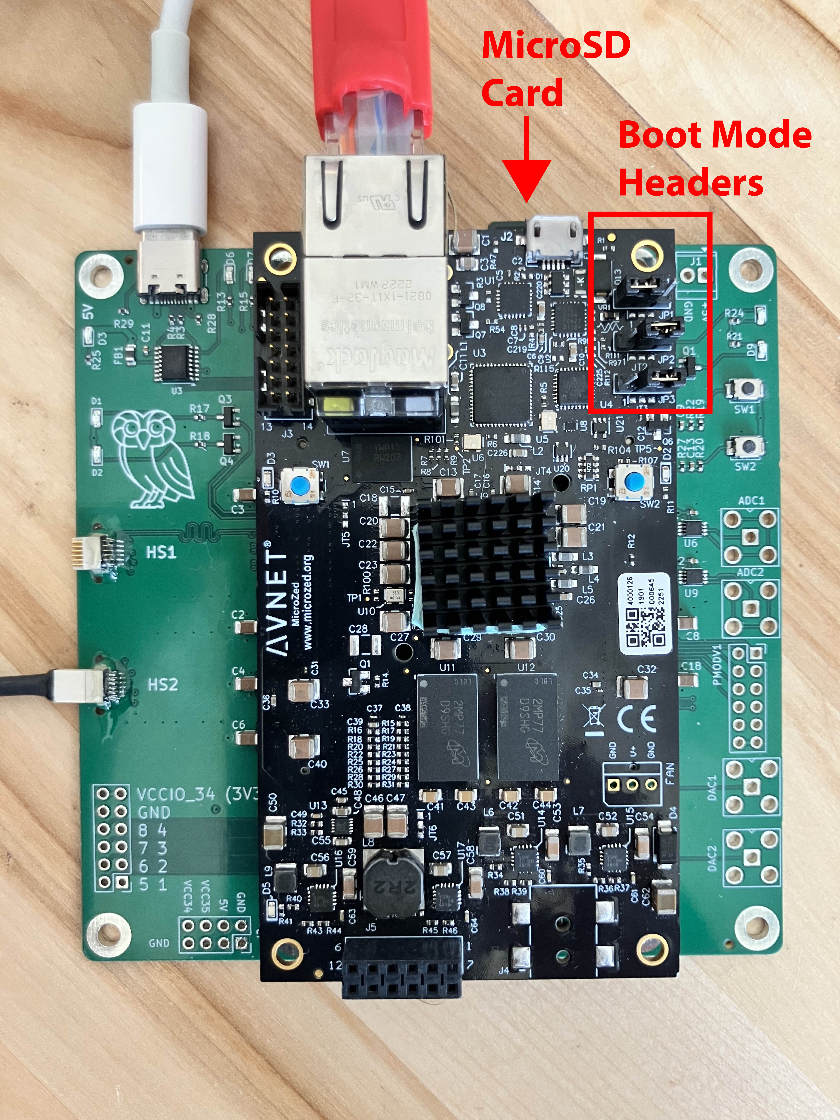
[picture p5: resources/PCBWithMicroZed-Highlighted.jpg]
  
</p>

### Set the VCCIO voltage switches (do this first)

The carrier has two **VCCIO bank-voltage switches** that must be set before powering a
headstage — the FPGA I/O banks physically drive at the selected voltage:

- **`VCCIO_35`** (at the **bottom end** of the carrier board) sets the voltage for the
  bank driving the **headstage** SPI. **Set it to `2V5` (2.5 V)** — RHD2000 headstages
  require 2.5 V I/O and will **not** work otherwise.
- **`VCCIO_34`** sets the voltage for the **PMOD** connector I/O. Set it to match what
  you attach there — either **3.3 V** or **2.5 V**.

> ⚠️ A wrong `VCCIO_35` is the most common "headstage doesn't respond / RESCAN finds
> nothing" cause — check this switch **first** if detection fails.

### Omnetics connector epoxy (do this)
The Omnetics 12-pin connector **requires epoxy reinforcement** — the pin-to-solder-pad
joints alone don't survive repeated mating. Apply several layers of UV-curing epoxy (we use
Bondic) to bond the connector body to the PCB; the through-holes by the connector are there
to anchor it. **Keep epoxy off the pins and the mating face.**

<p align="center">
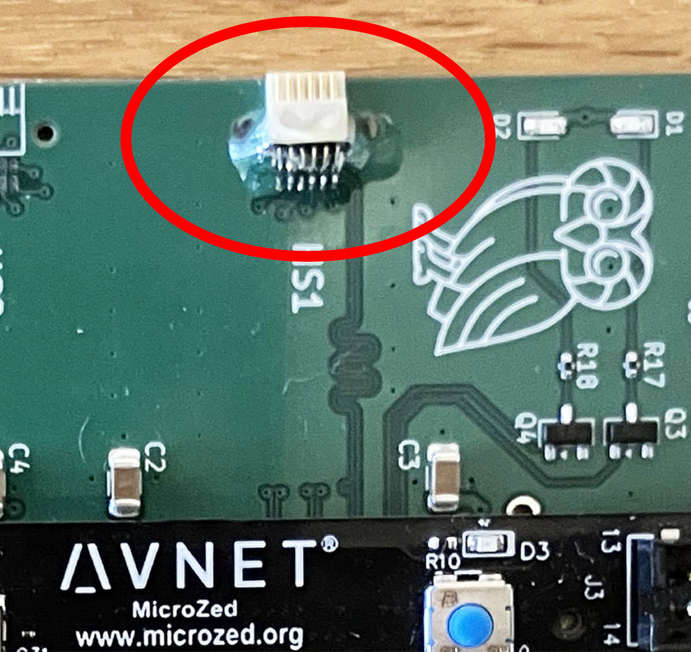
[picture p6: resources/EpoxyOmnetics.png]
  
</p>

## 2. MicroZed boot-mode jumpers (boot from SD)

The MicroZed selects its boot source with on-board jumpers. Set them for **SD-card boot**
as shown below:

<p align="center">
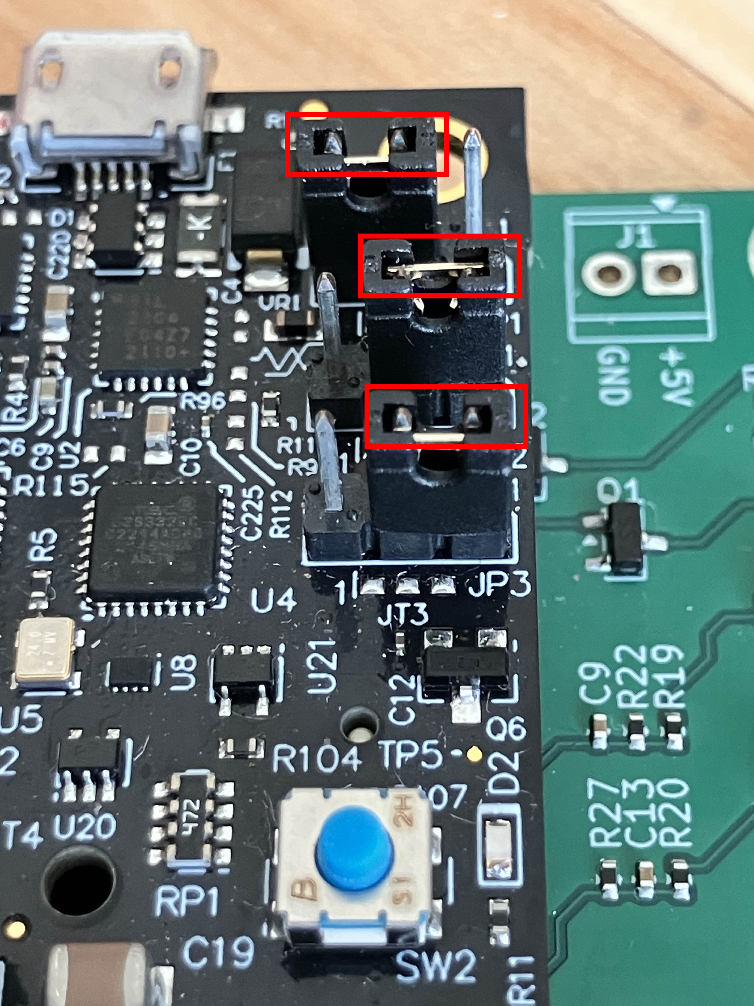
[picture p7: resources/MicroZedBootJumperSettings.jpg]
  
</p>

## 3. Put a bootable image on the SD card

The SD card needs a **FAT32** partition named **`Boot`** containing a `BOOT.bin`.

**Quickest — use the prebuilt image:** copy [`../blobs/BOOT.bin`](../blobs/BOOT.bin)
straight to the `Boot` partition. Insert the card, set the jumpers (step 2), power on.

**Or rebuild it** (see step 4), then:
```bash
bootgen -image scripts/boot.bif -o BOOT.bin -w   # produces BOOT.bin
cp BOOT.bin <SD Boot partition>/
```
`boot.bif` packs the FSBL + bitstream + both core ELFs. After **any PL change** the fresh
bitstream must be re-staged into the path `boot.bif` references before running `bootgen`
(see [`../CLAUDE.md`](../CLAUDE.md)).

## 4. Build from source (optional)

Needs **Vivado + Vitis 2025.1**.

```bash
# PL bitstream
source <vivado>/settings64.sh
vivado -mode batch -source scripts/create_vivado_project.tcl   # -> vivado_project/
vivado -mode batch -source scripts/build_bitstream.tcl         # -> vivado_project/klab_project.xsa

# PS firmware (both cores)
source <vitis>/settings64.sh
vitis -s scripts/create_vitis_project.py     # platform + both apps (clean vitis_workspace/ first)
vitis -s scripts/build_vitis_project.py      # incremental firmware-only rebuild
```
The part (`xc7z020clg400-1`) is set in `scripts/create_vivado_project.tcl`. A PL-only change
needs only a bitstream re-stage + `bootgen` (the firmware ELFs don't depend on PL clocks).
Full build notes and gotchas are in [`../CLAUDE.md`](../CLAUDE.md).

## 5. First connection

1. Plug in the USB-C (power) with the SD card inserted and wait for the Ethernet link. The
   **serial debug console** is on that same USB-C (115200 8N1) — open it in a terminal to
   watch boot/status messages (e.g. `CDMA: ready`, `CDMA: self-test OK`).
2. Put your host on the board's subnet (default board IP `192.168.18.10`).
3. Run the reference client:
   ```bash
   cd remote && python3 net.py      # connects to ZYNQ_IP (default 192.168.18.10)
   ```
   It auto-detects your host IP, points the board's UDP stream at you over TCP, and drops
   into an interactive prompt (`start`, `stop`, `get_status`, `auto_cable_detect`,
   `verify_sine`, …; type `help`). No chip needed — `set_debug 1` streams a synthetic sine.
4. For real recording/visualization use the **[ephys-socket](https://github.com/ckemere/ephys-socket)**
   OpenEphys plugin (drag **Intan Socket** in as the source, set the IP, **CONNECT** →
   **RESCAN** → play).

> ⚠️ **Don't run `net.py` and the OpenEphys plugin at the same time.** Both bind the
> same UDP data port (`0x6800`), so whichever is up consumes the datagrams. If `net.py`
> is running, the plugin will still **connect and look fine** (control is over TCP) but
> its data packets get **swallowed by `net.py`** — you'll see no (or partial) data in
> OpenEphys. Quit `net.py` before using the plugin.

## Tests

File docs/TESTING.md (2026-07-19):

# Testing & benchmarking

How to run the verification tooling for the broadband datapath. All RTL sims use
Vivado's `xsim` (`source /opt/Xilinx/2025.1/Vivado/settings64.sh` first); the
benchmarks run on the board and report over the serial console / `net.py`.

## RTL simulations (`programmable_logic/sim/`)

Each testbench has a `run_*.sh` that compiles the RTL it needs and runs `xsim`, then
prints `RESULT: PASS` / `RESULT: FAIL`.

```bash
cd programmable_logic/sim
source /opt/Xilinx/2025.1/Vivado/settings64.sh
bash run_dualport_dropout_tb.sh     # THE broadband integrity check (run this first)
```

| Testbench | `run_*.sh` | What it proves |
|---|---|---|
| `dualport_dropout_tb.sv` | `run_dualport_dropout_tb.sh` | **Broadband data integrity**: every data word out of the wrapper is byte‑exact vs the RTL sine reference across both cable ports, and SEQ/timestamp advance +1/packet with no gaps. This is the canonical "no dropout / no loss" proof. |
| `chirp_tb.sv` | `run_chirp_tb.sh` | The analytic **chirp NCO** (debug‑mode synthetic sweep) is bit‑exact vs the Python reference (`gen_chirp_vectors.py`). Captures the 35 data words/packet off the FIFO write interface (7‑word header skipped). |
| `fifo_bram_dualport_tb.sv` | `run_fifo_bram_dualport_tb.sh` | FIFO→BRAM dual‑port write/read path. |
| `aux_command_engine_tb.sv` | `run_aux_engine_tb.sh` | The merged **aux command engine** (banked looping store + real‑time fast‑settle / digout / DSP‑reset override + one‑shot injection), checked against expected values using the named roles from `acq_frame_pkg`. |
| `data_generator_aux_wire_tb.sv` | `run_aux_wire_tb.sh` | Aux **wire‑level integration**: decodes the serialized COPI out of the real core and verifies the always‑on aux commands (channel CONVERTs, the programmed aux loop, fast‑settle replace / D5‑force, injection) reach the chip. |
| `axi_lite_write_tb.sv`, `tb_axi_read_bram_ctrl.sv` | `run_axi_write_tb.sh`, `run_axi_read_sim.sh` | AXI‑Lite register write + BRAM‑controller read paths. |

Regenerate the chirp reference vectors (only if you change the NCO): `python3 gen_chirp_vectors.py`.

## BRAM‑read benchmark — *why DMA is required* (`benchmark_bram_reads.c`)

A bring‑up diagnostic that times the three ways of reading the capture BRAM, so you
can see for yourself why the shipped design uses **AXI‑CDMA** rather than the CPU.

Run it from the **serial debug console** (core‑1 UART, 115200 8N1):

```
benchmark
```

It reads a fixed block of packets from the capture BRAM via (a) word‑by‑word
`Xil_In32` single‑beat reads and (b) an `memcpy`/burst path, and prints the elapsed
time + throughput for each to the console. The takeaway: single‑beat reads over the
PS `M_AXI_GP` master cannot sustain the 0xFF (256‑ch, 150‑word) packet rate at the
131.25 MHz AXI clock, and CPU bursts of the BRAM corrupt the 0xFF stream — which is
why the real path moves the packet BRAM→DDR by CDMA (a PL master over `S_AXI_HP0`),
landing straight into the pbuf. (See `docs/bram_burst_read_bug.md` and the DMA rule
in `CLAUDE.md`.)

## check‑dma guardrail (`.claude/skills/check-dma/`)

A skill/script that scans for the anti‑pattern the benchmark above motivates: any
new PL→PS bulk‑data path that loops the CPU over BRAM/staging instead of using CDMA.
Run it before declaring a data‑path change done; genuinely‑justified single‑beat
peeks (e.g. a 2‑word magic/resync read) must be annotated `// DMA-EXEMPT: <reason>`.

## Host‑side (`remote/net.py`)

`python3 net.py` connects (TCP `0x6900`), starts streaming, and validates the
unified UDP stream (data on `0x6800`): per‑stream SEQ continuity (the loss check),
magic/size checks, and cable/phase detection. A clean run shows **0 SEQ gaps**.

> **UDP throughput benchmark** (board‑side blaster + `net.py` meter for MB/s vs
> packet size) is a separate tool being re‑added on top of this branch — it needs a
> dedicated bench port in the new `0x68xx` scheme and is best validated with a live
> host‑side throughput measurement.

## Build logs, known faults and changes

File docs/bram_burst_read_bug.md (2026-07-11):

# BRAM burst-read corruption — problem & task brief

> **RESOLVED (fw 1.1.0.0).** The fix is **AXI CDMA**, not the chunked read this brief
> proposes: a PL master (CDMA) reads the capture BRAM and writes DDR over S_AXI_HP0,
> taking the corrupting PS M_AXI_GP master off the data path entirely. The earlier
> chunked/`ldmia` CPU reads were dead ends (still bursts over the broken GP master).
> See `docs/custom_axi_bram_ctrl_decision.md` and `firmware/src-core0/pl_dma.c`. The
> root-cause analysis below remains accurate and is kept as the record.

Status: **RESOLVED via DMA** (historical: "candidate fix in test", chunked read).
Audience: a Claude Code instance picking this up, possibly with hardware attached.

## TL;DR

When streaming the **full dual-port `0xFF`** configuration (8 streams, 150-word /
600-byte packets), a small, localized run of samples comes out as out-of-range
garbage. Smaller configs (`0x0F` 80-word, `0x3F` 115-word packets) are clean.

**Root cause (proven):** the PS core-0 reads the capture BRAM with `memcpy`, which
issues **long AXI bursts over the M_AXI_GP port**. Long GP-port bursts
intermittently corrupt one short run of beats. It is **not** the BRAM, **not**
read-during-write, **not** the clock, **not** cache.

**Quick fix (in test):** read the packet in small `memcpy` chunks
(`BRAM_READ_CHUNK_WORDS = 8` in `firmware/src-core0/main.c`), each a short burst
below the length that triggers the corruption.

**Real fix (next):** move BRAM→DDR onto a **PL DMA** (e.g. `axi_datamover`) so the
CPU GP port is off the data path entirely.

## The system (1 paragraph)

MicroZed (Zynq-7020, `xc7z020clg400-1`). PL acquires Intan RHD2000 data and writes
packets into a 64 KB capture BRAM (`0x80000000`). PS core 0 polls the BRAM, copies
each packet to a DDR buffer, and UDP-streams it (port 0x6800); core 1 is the serial
debug console. Host control + capture is `remote/net.py` (TCP 0x6900). Read
`overview.txt` and `CLAUDE.md` for the full picture and the 3-layer
register/packet contract.

## How we proved the root cause

1. **`verify_sine`** (a `net.py` command): puts the board in debug mode (synthetic
   sine, no chip needed) and compares every received 16-bit sample to an
   RTL-exact reference. At `0xFF` it reports ~3.2% of samples wrong, **out of LUT
   range**, clustered at packet **words ~116–128** (decode to cycles 26–29 →
   de-skewed channels 24–27 of each of the 8 stream blocks — the glitch bands you
   see in Open Ephys). 0% packet loss. `0x0F`/`0x3F` pass.
2. **`dump_bram <addr> <count>`** (serial command, `pl_dump_bram_data`): reads the
   same BRAM region **two ways** — `memcpy` (AXI burst) and `Xil_In32`
   (single beats) — and flags diffs. **On a STOPPED board** (no PL writing), the
   `memcpy` burst returns garbage at a short run of words while the single reads
   read the same addresses correctly. That rules out read-during-write and the
   BRAM content; it is the burst transaction itself.
3. **`dump_bram 0 10` is always clean; `dump_bram 0 20` corrupts at words 12–15.**
   So reads stay clean below ~11 words and corrupt at ≥ ~12. Only `0xFF`'s
   150-word read is long enough to reach the corrupt offset.
4. **`report_timing`** on the routed design: the BRAM read path is healthy
   (+2.357 ns data, +1.74 ns address; not false-pathed). The worst path in the
   design is the SPI COPI output at +0.133 ns, unrelated. So timing / output
   registers on the BRAM are **not** the fix.

The corrupted values (`0x0404/0408/0624/0628`, DDR halves zero) are an AXI-path
artifact, not memory content — they appeared identically on a zero-initialized
vendor `blk_mem_gen`, so don't read meaning into the values; the **positions** are
what matter.

## Dead ends — do NOT re-chase these (each was built + tested on hardware)

- **Vendor BRAM** (`blk_mem_gen` swap): same corruption → not the BRAM primitive.
- **Cache**: making the BRAM non-cacheable only *shifted* the offset by one cache
  line → cache is not the source (it reshapes the burst).
- **Clock / phase**: 175 MHz did **not** fix it and *spread* the corruption onto
  the header timestamp (causing `net.py` errors that the firmware's magic-only
  validation doesn't see). Reverted to 131.25 MHz.
- **Write-pointer CDC deglitch** and **read-pointer guard band**: each only moved
  the corruption. Kept as harmless hygiene.
- **Read-during-write / BRAM timing margin / output register**: ruled out by the
  STOPPED-board reproduction and the +2.3 ns timing slack.

## Current state of the branch (`claude/dual-port`)

- Firmware read is a **chunked `memcpy`** (`BRAM_READ_CHUNK_WORDS = 8`).
- AXI clock at **131.25 MHz** (clean timing, WNS ~+0.13).
- Custom `simple_dual_port_bram` (vendor swap reverted; it's not at fault).
- **Stop/restart fix**: `handle_enable_streaming` scans back from the write pointer
  to the real `0xDEADBEEF/0xCAFEBABE` magic to re-sync `ps_read` (the datapath's
  write_address/FIFO are only cleared by the hardware reset, so a stop mid-packet
  used to leave `ps_read` a few words off the boundary → endless
  `Magic validation failed (0x..11CE8)` loop).
- Diagnostic kept: `dump_bram` shows `burst | single | flag` and a diff count.
- Pre-built image: `blobs/BOOT.bin`.

## Remaining task list

1. **Verify the chunked fix** on hardware: `verify_sine 0xFF` → expect
   `VALUE CHECK: PASS` and `PACKET LOSS: PASS`. Check Open Ephys glitch bands gone.
   Check start/stop/restart is clean.
2. **Tune `BRAM_READ_CHUNK_WORDS`**: if clean + no loss, raise it (10, then higher)
   re-checking `verify_sine` each step to find the largest safe/ fastest burst; if
   any diffs survive, drop to 4. Firmware-only, minutes per iteration.
3. **DMA (real fix)**: add an `axi_datamover`/`axi_dma` PL master to copy
   BRAM→DDR with controlled bursts, freeing core 0. Verify it doesn't reintroduce
   the GP-port pattern (it reads through the same `axi_bram_ctrl` but as a
   different, well-formed master). Bitstream + firmware change.
4. Re-confirm `0x0F`/`0x3F` still pass (no regression) and the plugin
   (`ephys-socket`, branch `claude/dual-port-plugin`) streams cleanly.

## Key tools

- `remote/net.py` → `verify_sine [ce=FF] [n]` (the ground-truth value checker),
  `set_channels`, `set_debug`, `start`/`stop`, `dump_bram <word> <count>`.
- Serial debug console (core 1) shows firmware messages and `dump_bram` output.
- Build: `scripts/create_vivado_project.tcl` + `scripts/build_bitstream.tcl` (PL),
  `scripts/create_vitis_project.py` (platform + both apps; clean `vitis_workspace`
  first), `scripts/build_vitis_project.py` (firmware-only incremental),
  `bootgen -image scripts/boot.bif -o BOOT.bin -w`.

## Hard rule

**Data fidelity:** never alter acquired sample values (no detrend/baseline/filter/
offset) without explicit approval. Fix display via scale factors / viewer ranges.

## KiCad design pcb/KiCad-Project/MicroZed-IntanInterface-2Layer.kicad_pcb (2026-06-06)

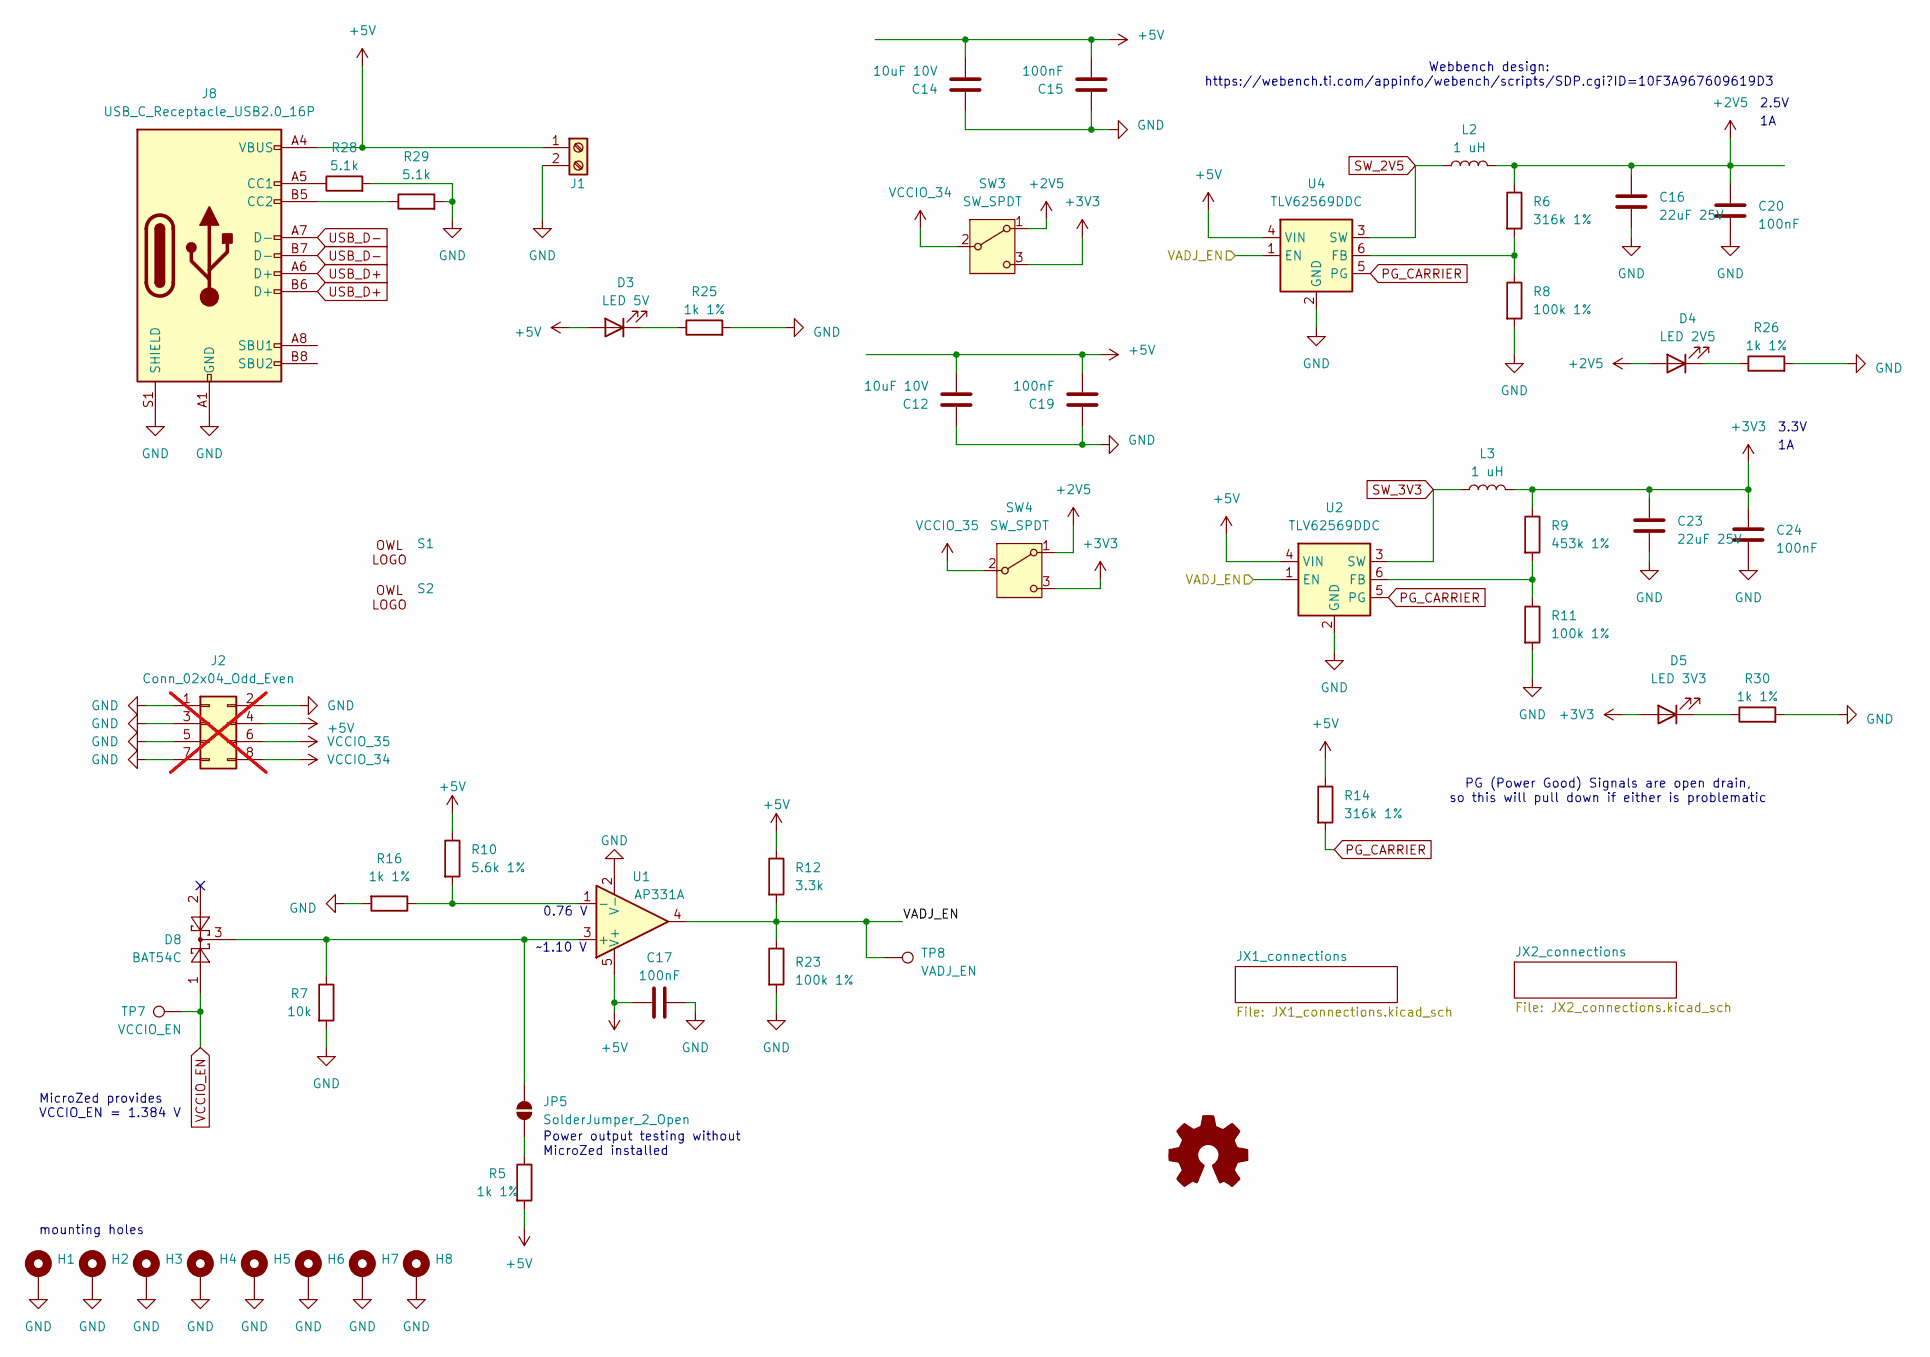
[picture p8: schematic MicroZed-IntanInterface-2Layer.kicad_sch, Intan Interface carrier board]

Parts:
C12, C14: 10uF 10V; C_0603_1608Metric; LCSC C19702
C15, C17, C19, C20, C24: 100nF; C_0402_1005Metric; LCSC C307331
C16, C23: 22uF 25V; C_1206_3216Metric; LCSC C12891
D3: LED 5V; LED_0603_1608Metric; LCSC C2286
D4: LED 2V5; LED_0603_1608Metric; LCSC C2286
D5: LED 3V3; LED_0603_1608Metric; LCSC C2286
D8: BAT54C; SOT-23; LCSC C37704
H1, H2, H3, H4, H5, H6, H7, H8: MountingHole_3.2mm_M3_Pad
J1: Screw_Terminal_01x02; TerminalBlock_TE_282834-2_1x02_P2.54mm_Horizontal
J2: Conn_02x04_Odd_Even; PinSocket_2x04_P2.54mm_Vertical; not fitted
J8: USB_C_Receptacle_USB2.0_16P; USB_C_Receptacle_GCT_USB4105-xx-A_16P_TopMnt_Horizontal; LCSC C5184243
JP5: SolderJumper_2_Open; SolderJumper-2_P1.3mm_Open_RoundedPad1.0x1.5mm
L2, L3: 1 uH; L_1210_3225Metric; LCSC C47492669
R5, R16, R25, R26, R30: 1k 1%; R_0402_1005Metric; LCSC C11702
R6, R14: 316k 1%; R_0402_1005Metric; LCSC C4338094
R7: 10k; R_0402_1005Metric; LCSC C25744
R8, R11, R23: 100k 1%; R_0402_1005Metric; LCSC C25741
R9: 453k 1%; R_0402_1005Metric; LCSC C3025678
R10: 5.6k 1%; R_0402_1005Metric; LCSC C25908
R12: 3.3k; R_0402_1005Metric; LCSC C25890
R28, R29: 5.1k; R_0402_1005Metric; LCSC C25905
S1, S2: RICE_OWL_LOGO; not fitted
SW3, SW4: SW_SPDT; SW_SPDT_PCM12; LCSC C221841
TP7: VCCIO_EN; TestPoint_THTPad_D2.0mm_Drill1.0mm
TP8: VADJ_EN; TestPoint_THTPad_D2.0mm_Drill1.0mm
U1: AP331A; SOT-25-5_L3.0-W1.8-P0.95-LS3.0-BR; LCSC C151034
U2, U4: TLV62569DDC; SOT-23-6; LCSC C398365

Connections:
+2V5: C16.2, C20.1, D4.2 (A), L2.2, R6.1, SW3.1 (A), SW4.1 (A)
+3V3: C23.2, C24.1, D5.2 (A), L3.2, R9.1, SW3.3 (C), SW4.3 (C); also elsewhere on the board
+5V: C12.1, C14.1, C15.2, C17.1, C19.2, D3.2 (A), J1.1, J2.4, J8.A4 (VBUS), J8.A9 (VBUS), J8.B4 (VBUS), J8.B9 (VBUS), R5.2, R10.1, R12.1, R14.1, U1.5 (V+), U2.4 (VIN), U4.4 (VIN); also elsewhere on the board
/VADJ_EN: R12.2, R23.1, TP8.1, U1.4, U2.1 (EN), U4.1 (EN)
GND: C12.2, C14.2, C15.1, C16.1, C17.2, C19.1, C20.2, C23.1, C24.2, H1.1, H2.1, H3.1, H4.1, H5.1, H6.1, H7.1, H8.1, J1.2, J2.1, J2.2, J2.3, J2.5, J2.7, J8.A1 (GND), J8.A12 (GND), J8.B1 (GND), J8.B12 (GND), J8.S1 (SHIELD), R7.2, R8.2, R11.2, R16.2, R23.2, R25.2, R26.2, R28.2, R29.2, R30.2, U1.2 (V-), U2.2 (GND), U4.2 (GND); also elsewhere on the board
unnamed: D3.1 (K), R25.1
unnamed: D4.1 (K), R26.1
unnamed: D5.1 (K), R30.1
unnamed: J8.A5 (CC1), R28.1
unnamed: J8.B5 (CC2), R29.1
unnamed: D8.3, JP5.1 (A), R7.1, U1.3 (+)
unnamed: JP5.2 (B), R5.1
unnamed: R10.2, R16.1, U1.1 (-)
unnamed: R9.2, R11.1, U2.6 (FB)
unnamed: R6.2, R8.1, U4.6 (FB)
PG_CARRIER: R14.2, U2.5 (PG), U4.5 (PG); also elsewhere on the board
SW_2V5: L2.1, U4.3 (SW)
SW_3V3: L3.1, U2.3 (SW)
USB_D+: J8.A6 (D+), J8.B6 (D+); also elsewhere on the board
USB_D-: J8.A7 (D-), J8.B7 (D-); also elsewhere on the board
VCCIO_34: J2.8, SW3.2 (B); also elsewhere on the board
VCCIO_35: J2.6, SW4.2 (B); also elsewhere on the board
VCCIO_EN: D8.1, TP7.1; also elsewhere on the board

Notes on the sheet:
3.3V
mounting holes
2.5V
0.76 V
Webbench design: https://webench.ti.com/appinfo/webench/scripts/SDP.cgi?ID=10F3A967609619D3
~1.10 V
Power output testing without MicroZed installed
MicroZed provides VCCIO_EN = 1.384 V
PG (Power Good) Signals are open drain, so this will pull down if either is problematic

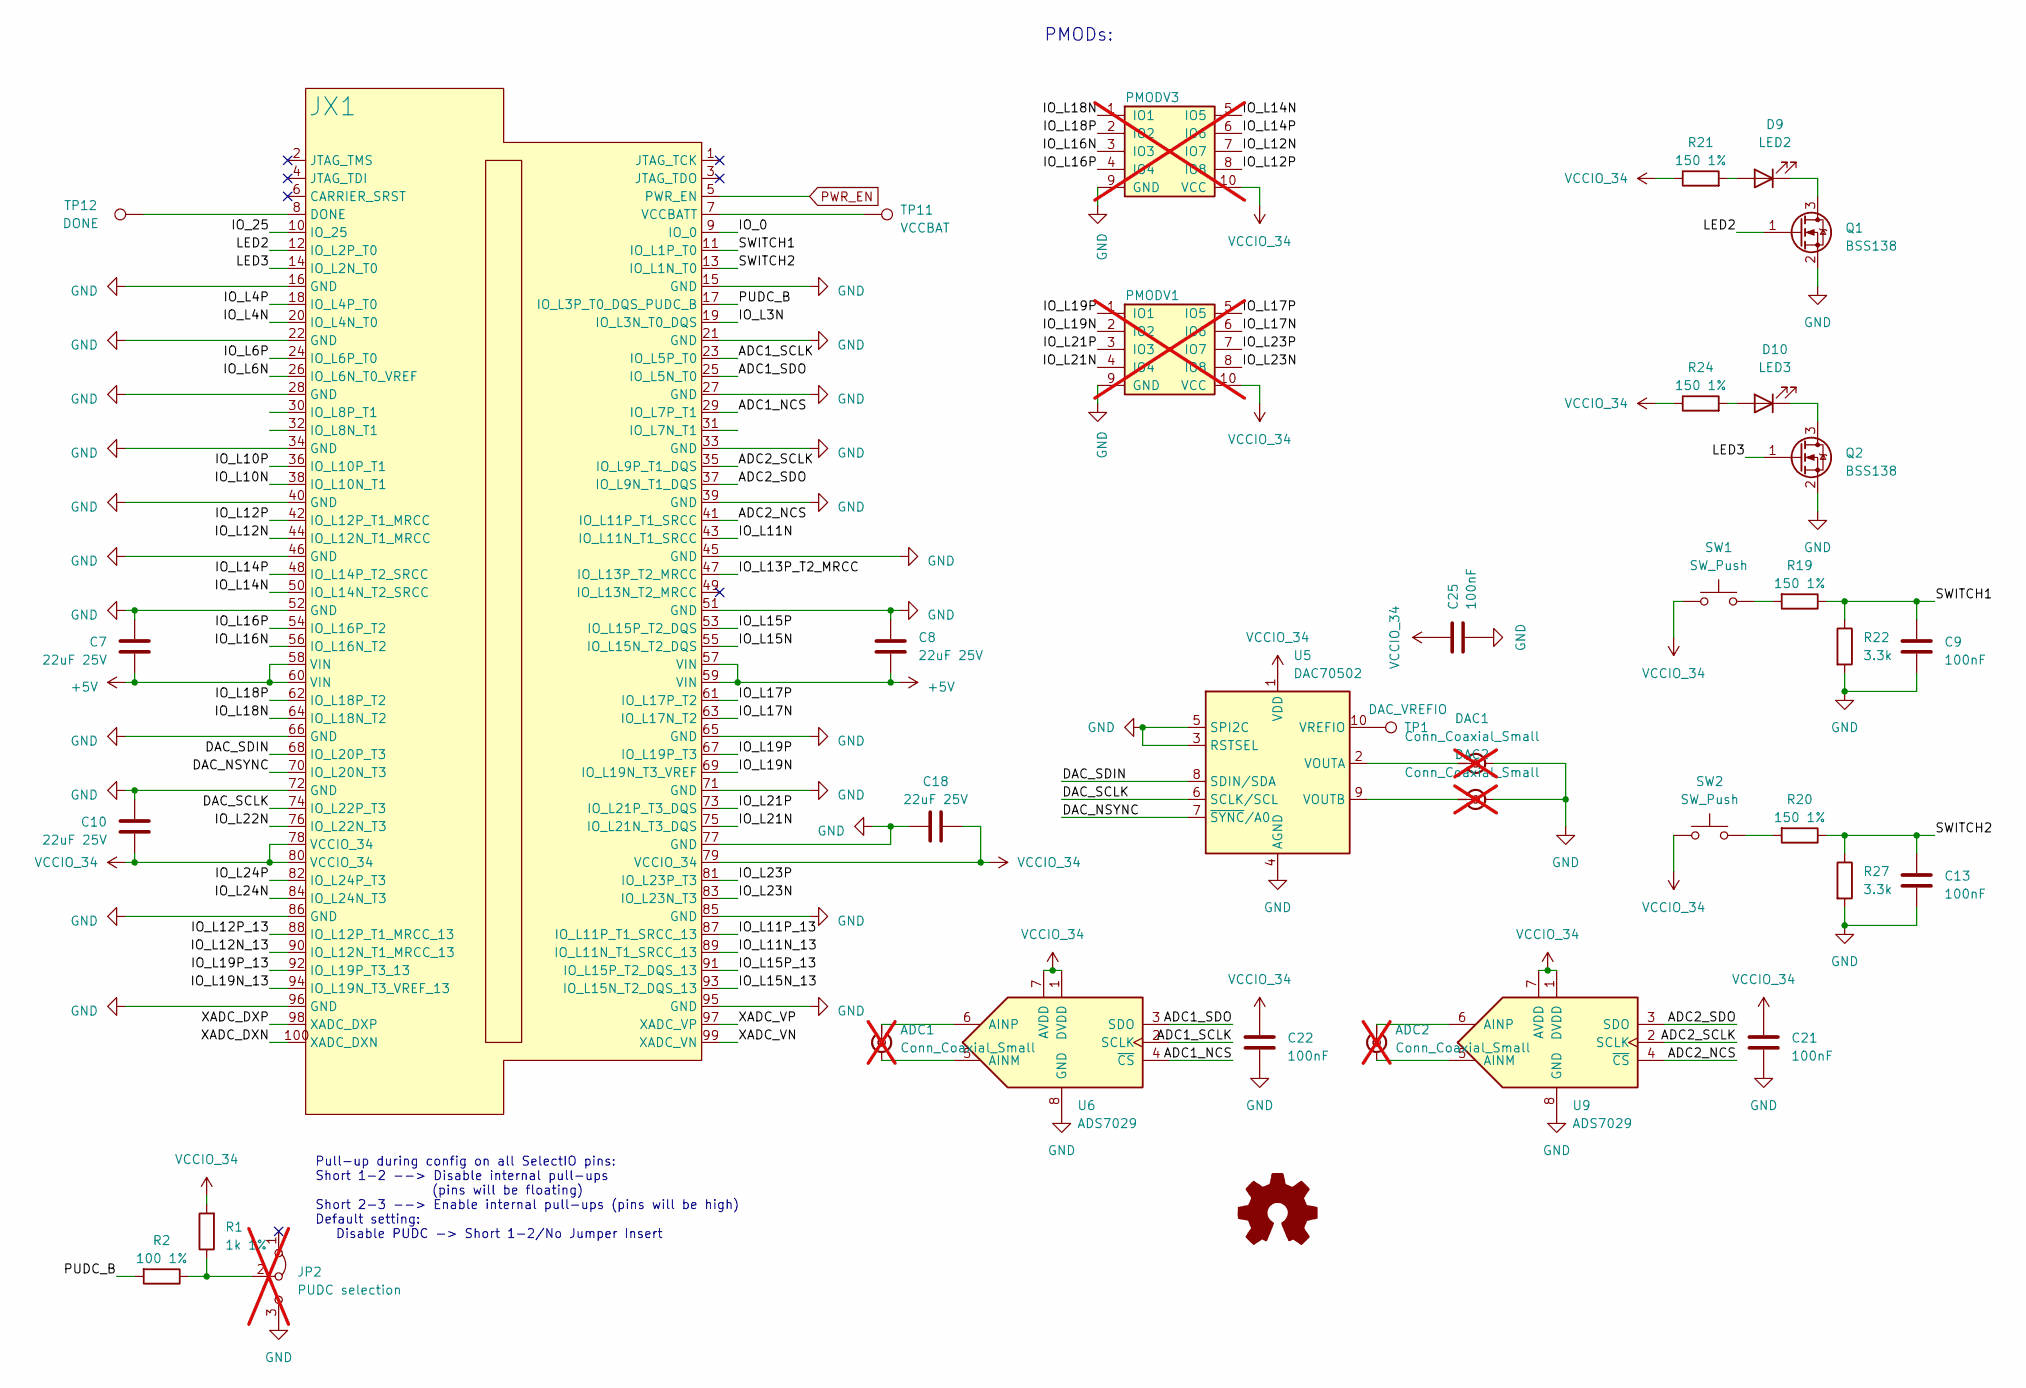
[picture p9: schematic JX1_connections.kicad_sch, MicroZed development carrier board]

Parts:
ADC1, ADC2: Conn_Coaxial_Small; SMA_Amphenol_901-143_Horizontal; not fitted
C7, C8, C10, C18: 22uF 25V; C_1206_3216Metric; LCSC C12891
C9, C13, C21, C22, C25: 100nF; C_0402_1005Metric; LCSC C307331
D9: LED2; LED_0603_1608Metric; LCSC C2286
D10: LED3; LED_0603_1608Metric; LCSC C2286
DAC1, DAC2: Conn_Coaxial_Small; SMA_Amphenol_901-143_Horizontal; not fitted
JP2: PUDC selection; PinHeader_1x03_P2.54mm_Vertical; not fitted
JX1: BergStak-100pos-plug-61083-101400; LCSC C2764776
PMODV1: PinSocket_2x06_P2.54mm_Vertical; not fitted
PMODV3: PMOD_Socket_Vertical; not fitted
Q1, Q2: BSS138; SOT-23; LCSC C400505
R1: 1k 1%; R_0402_1005Metric; LCSC C11702
R2: 100 1%; R_0402_1005Metric; LCSC C25076
R19, R20, R21, R24: 150 1%; R_0402_1005Metric; LCSC C25082
R22, R27: 3.3k; R_0402_1005Metric; LCSC C25890
SW1, SW2: SW_Push; SW_SPST_TS-1088-xR020; LCSC C720477
TP1: DAC_VREFIO; TestPoint_THTPad_D2.0mm_Drill1.0mm
TP11: VCCBAT; TestPoint_THTPad_D2.0mm_Drill1.0mm
TP12: DONE; TestPoint_THTPad_D2.0mm_Drill1.0mm
U5: DAC70502; Texas_DRX_WSON-10_2.5x2.5mm_P0.5mm; LCSC C880348
U6, U9: ADS7029; VSSOP-8_2.3x2mm_P0.5mm; LCSC C2669867

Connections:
+5V: C7.1, C8.1, JX1.57 (VIN), JX1.58 (VIN), JX1.59 (VIN), JX1.60 (VIN); also elsewhere on the board
/JX1_connections/ADC1_NCS: JX1.29 (IO_L7P_T1), U6.4 (~CS)
/JX1_connections/ADC1_SCLK: JX1.23 (IO_L5P_T0), U6.2 (SCLK)
/JX1_connections/ADC1_SDO: JX1.25 (IO_L5N_T0), U6.3 (SDO)
/JX1_connections/ADC2_NCS: JX1.41 (IO_L11P_T1_SRCC), U9.4 (~CS)
/JX1_connections/ADC2_SCLK: JX1.35 (IO_L9P_T1_DQS), U9.2 (SCLK)
/JX1_connections/ADC2_SDO: JX1.37 (IO_L9N_T1_DQS), U9.3 (SDO)
/JX1_connections/DAC_NSYNC: JX1.70 (IO_L20N_T3), U5.7 (~SYNC/A0)
/JX1_connections/DAC_SCLK: JX1.74 (IO_L22P_T3), U5.6 (SCLK/SCL)
/JX1_connections/DAC_SDIN: JX1.68 (IO_L20P_T3), U5.8 (SDIN/SDA)
/JX1_connections/IO_0: JX1.9 (IO_0)
/JX1_connections/IO_25: JX1.10 (IO_25)
/JX1_connections/IO_L3N: JX1.19 (IO_L3N_T0_DQS)
/JX1_connections/IO_L4N: JX1.20 (IO_L4N_T0)
/JX1_connections/IO_L4P: JX1.18 (IO_L4P_T0)
/JX1_connections/IO_L6N: JX1.26 (IO_L6N_T0_VREF)
/JX1_connections/IO_L6P: JX1.24 (IO_L6P_T0)
/JX1_connections/IO_L10N: JX1.38 (IO_L10N_T1)
/JX1_connections/IO_L10P: JX1.36 (IO_L10P_T1)
/JX1_connections/IO_L11N: JX1.43 (IO_L11N_T1_SRCC)
/JX1_connections/IO_L11N_13: JX1.89 (IO_L11N_T1_SRCC_13)
/JX1_connections/IO_L11P_13: JX1.87 (IO_L11P_T1_SRCC_13)
/JX1_connections/IO_L12N: JX1.44 (IO_L12N_T1_MRCC), PMODV3.7 (IO7)
/JX1_connections/IO_L12N_13: JX1.90 (IO_L12N_T1_MRCC_13)
/JX1_connections/IO_L12P: JX1.42 (IO_L12P_T1_MRCC), PMODV3.8 (IO8)
/JX1_connections/IO_L12P_13: JX1.88 (IO_L12P_T1_MRCC_13)
/JX1_connections/IO_L13P_T2_MRCC: JX1.47 (IO_L13P_T2_MRCC)
/JX1_connections/IO_L14N: JX1.50 (IO_L14N_T2_SRCC), PMODV3.5 (IO5)
/JX1_connections/IO_L14P: JX1.48 (IO_L14P_T2_SRCC), PMODV3.6 (IO6)
/JX1_connections/IO_L15N: JX1.55 (IO_L15N_T2_DQS)
/JX1_connections/IO_L15N_13: JX1.93 (IO_L15N_T2_DQS_13)
/JX1_connections/IO_L15P: JX1.53 (IO_L15P_T2_DQS)
/JX1_connections/IO_L15P_13: JX1.91 (IO_L15P_T2_DQS_13)
/JX1_connections/IO_L16N: JX1.56 (IO_L16N_T2), PMODV3.3 (IO3)
/JX1_connections/IO_L16P: JX1.54 (IO_L16P_T2), PMODV3.4 (IO4)
/JX1_connections/IO_L17N: JX1.63 (IO_L17N_T2), PMODV1.6 (IO6)
/JX1_connections/IO_L17P: JX1.61 (IO_L17P_T2), PMODV1.5 (IO5)
/JX1_connections/IO_L18N: JX1.64 (IO_L18N_T2), PMODV3.1 (IO1)
/JX1_connections/IO_L18P: JX1.62 (IO_L18P_T2), PMODV3.2 (IO2)
/JX1_connections/IO_L19N: JX1.69 (IO_L19N_T3_VREF), PMODV1.2 (IO2)
/JX1_connections/IO_L19N_13: JX1.94 (IO_L19N_T3_VREF_13)
/JX1_connections/IO_L19P: JX1.67 (IO_L19P_T3), PMODV1.1 (IO1)
/JX1_connections/IO_L19P_13: JX1.92 (IO_L19P_T3_13)
/JX1_connections/IO_L21N: JX1.75 (IO_L21N_T3_DQS), PMODV1.4 (IO4)
/JX1_connections/IO_L21P: JX1.73 (IO_L21P_T3_DQS), PMODV1.3 (IO3)
/JX1_connections/IO_L22N: JX1.76 (IO_L22N_T3)
/JX1_connections/IO_L23N: JX1.83 (IO_L23N_T3), PMODV1.8 (IO8)
/JX1_connections/IO_L23P: JX1.81 (IO_L23P_T3), PMODV1.7 (IO7)
/JX1_connections/IO_L24N: JX1.84 (IO_L24N_T3)
/JX1_connections/IO_L24P: JX1.82 (IO_L24P_T3)
/JX1_connections/LED2: JX1.12 (IO_L2P_T0), Q1.1 (G)
/JX1_connections/LED3: JX1.14 (IO_L2N_T0), Q2.1 (G)
/JX1_connections/PUDC_B: JX1.17 (IO_L3P_T0_DQS_PUDC_B), R2.2
/JX1_connections/SWITCH1: C9.1, JX1.11 (IO_L1P_T0), R19.1, R22.1
/JX1_connections/SWITCH2: C13.1, JX1.13 (IO_L1N_T0), R20.1, R27.1
/JX1_connections/XADC_DXN: JX1.100 (XADC_DXN)
/JX1_connections/XADC_DXP: JX1.98 (XADC_DXP)
/JX1_connections/XADC_VN: JX1.99 (XADC_VN)
/JX1_connections/XADC_VP: JX1.97 (XADC_VP)
GND: C7.2, C8.2, C9.2, C10.2, C13.2, C18.2, C21.2, C22.2, C25.2, DAC1.2 (Ext), DAC2.2 (Ext), JP2.3 (B), JX1.15 (GND), JX1.16 (GND), JX1.21 (GND), JX1.22 (GND), JX1.27 (GND), JX1.28 (GND), JX1.33 (GND), JX1.34 (GND), JX1.39 (GND), JX1.40 (GND), JX1.45 (GND), JX1.46 (GND), JX1.51 (GND), JX1.52 (GND), JX1.65 (GND), JX1.66 (GND), JX1.71 (GND), JX1.72 (GND), JX1.77 (GND), JX1.85 (GND), JX1.86 (GND), JX1.95 (GND), JX1.96 (GND), PMODV1.9 (GND), PMODV3.9 (GND), Q1.2 (S), Q2.2 (S), R22.2, R27.2, U5.3 (RSTSEL), U5.4 (AGND), U5.5 (SPI2C), U6.8 (GND), U9.8 (GND); also elsewhere on the board
unnamed: ADC1.2 (Ext), U6.5 (AINM)
unnamed: ADC1.1 (In), U6.6 (AINP)
unnamed: ADC2.2 (Ext), U9.5 (AINM)
unnamed: ADC2.1 (In), U9.6 (AINP)
unnamed: D9.2 (A), R21.2
unnamed: D9.1 (K), Q1.3 (D)
unnamed: D10.2 (A), R24.2
unnamed: D10.1 (K), Q2.3 (D)
unnamed: DAC1.1 (In), U5.2 (VOUTA)
unnamed: DAC2.1 (In), U5.9 (VOUTB)
unnamed: JP2.2 (C), R1.1, R2.1
unnamed: JX1.8 (DONE), TP12.1
unnamed: JX1.7 (VCCBATT), TP11.1
unnamed: R19.2, SW1.2
unnamed: R20.2, SW2.2
unnamed: TP1.1, U5.10 (VREFIO)
PWR_EN: JX1.5 (PWR_EN)
VCCIO_34: C10.1, C18.1, C21.1, C22.1, C25.1, JX1.78 (VCCIO_34), JX1.79 (VCCIO_34), JX1.80 (VCCIO_34), PMODV1.10 (VCC), PMODV3.10 (VCC), R1.2, R21.1, R24.1, SW1.1, SW2.1, U5.1 (VDD), U6.1 (DVDD), U6.7 (AVDD), U9.1 (DVDD), U9.7 (AVDD); also elsewhere on the board

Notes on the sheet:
PMODs:
Pull-up during config on all SelectIO pins: Short 1-2 --> Disable internal pull-ups (pins will be floating) Short 2-3 --> Enable internal pull-ups (pins will be high) Default setting: Disable PUDC -> Short 1-2/No Jumper Insert

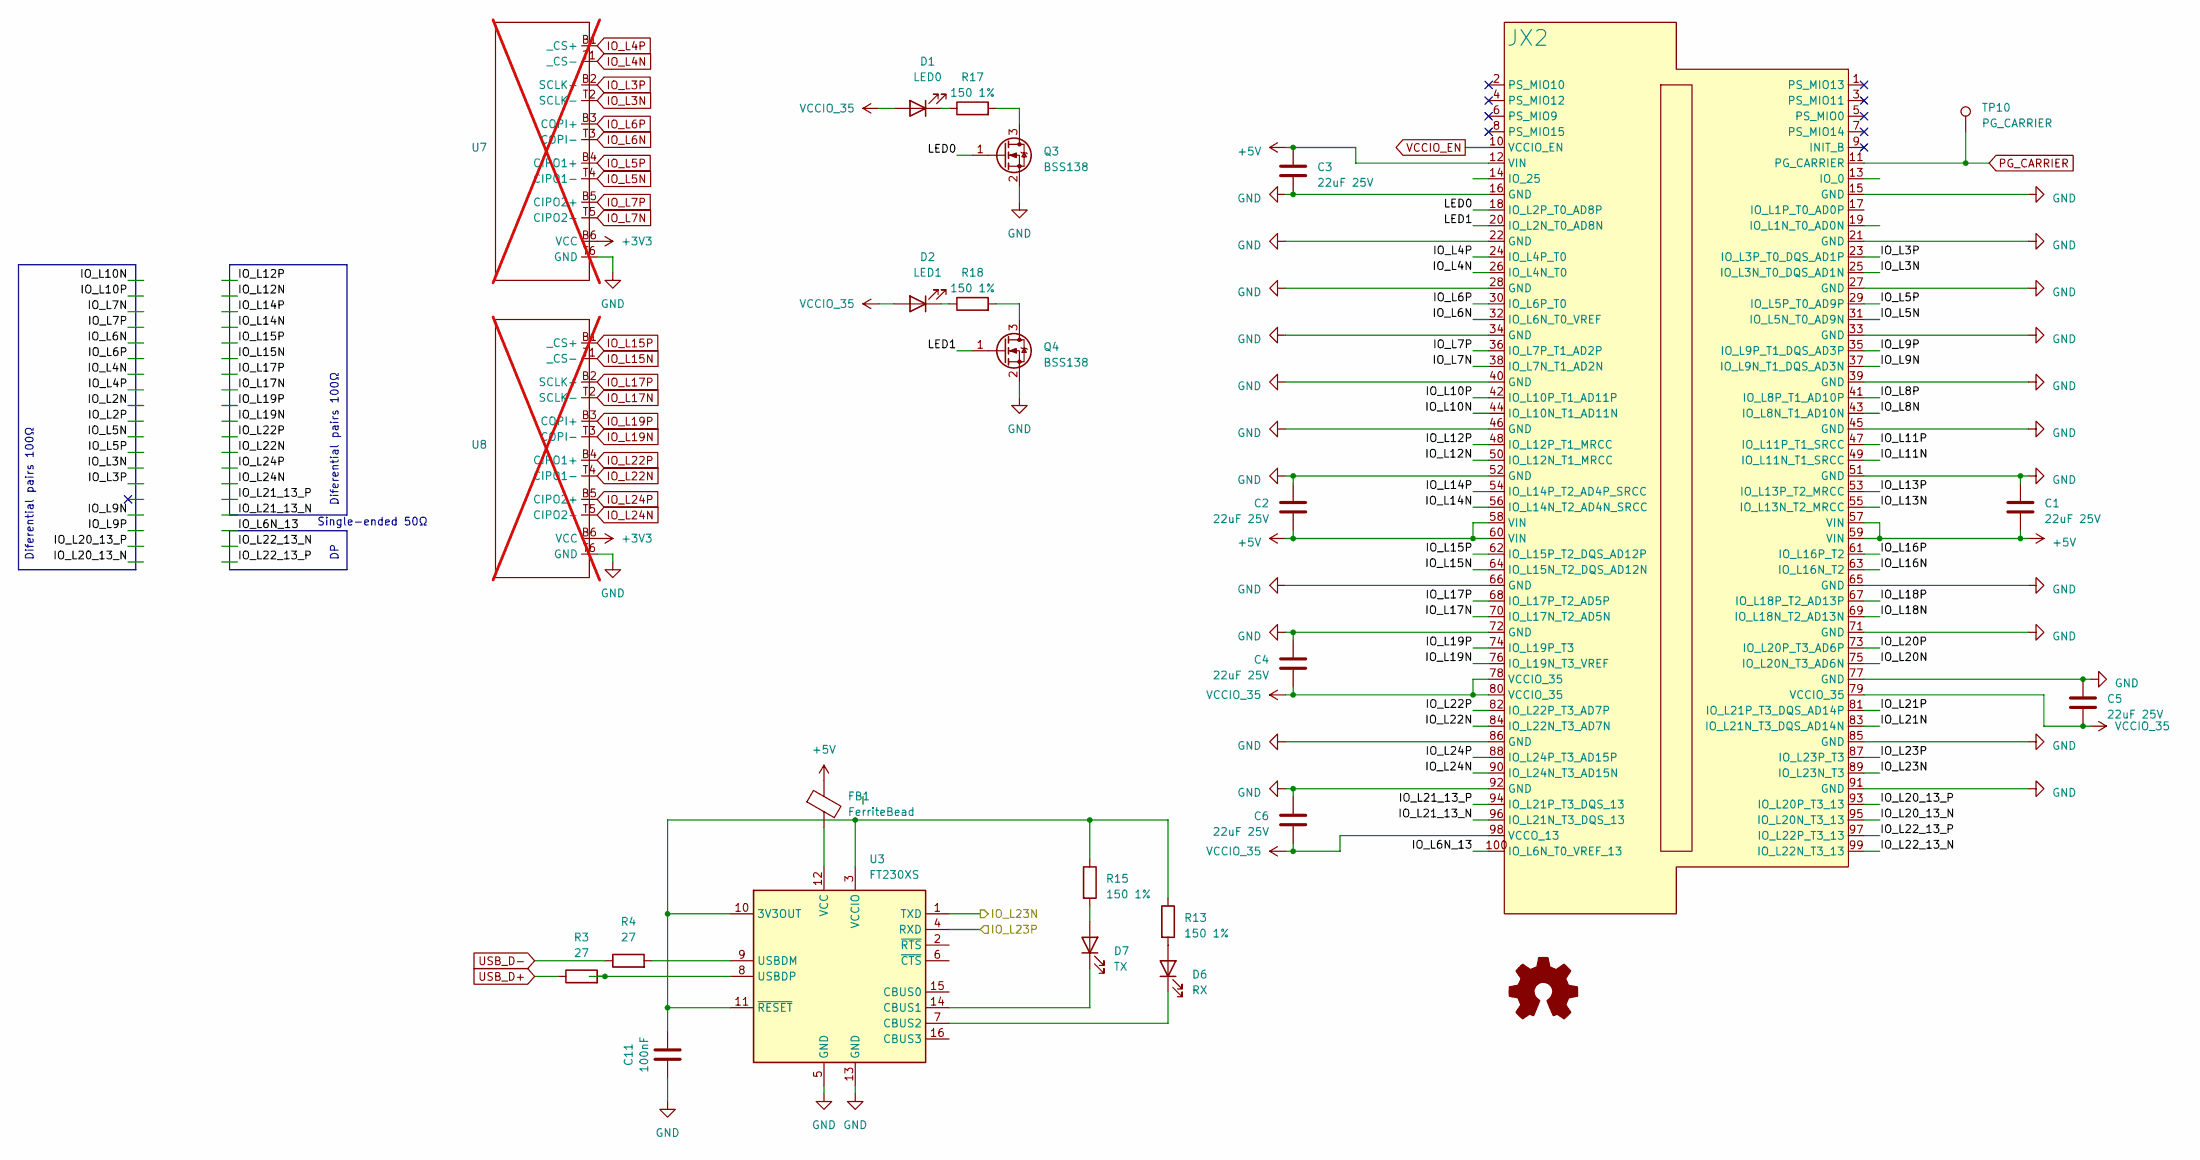
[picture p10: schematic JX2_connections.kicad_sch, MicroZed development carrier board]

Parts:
C1, C2, C3, C4, C5, C6: 22uF 25V; C_1206_3216Metric; LCSC C12891
C11: 100nF; C_0402_1005Metric; LCSC C307331
D1: LED0; LED_0603_1608Metric; LCSC C2286
D2: LED1; LED_0603_1608Metric; LCSC C2286
D6: RX; LED_0603_1608Metric; LCSC C2286
D7: TX; LED_0603_1608Metric; LCSC C2286
FB1: FerriteBead; L_0805_2012Metric; LCSC C85840
JX2: BergStak-100pos-plug-61083-101400; LCSC C2764776
Q3, Q4: BSS138; SOT-23; LCSC C400505
R3, R4: 27; R_0402_1005Metric; LCSC C413051
R13, R15, R17, R18: 150 1%; R_0402_1005Metric; LCSC C25082
TP10: PG_CARRIER; TestPoint_THTPad_D2.0mm_Drill1.0mm
U3: FT230XS; SSOP-16_3.9x4.9mm_P0.635mm; LCSC C69082
U7, U8: OMNETICS_PZN-12-AA; not fitted

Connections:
+3V3: U7.B6 (VCC), U8.B6 (VCC); also elsewhere on the board
+5V: C1.1, C2.1, C3.1, FB1.1, JX2.12 (VIN), JX2.57 (VIN), JX2.58 (VIN), JX2.59 (VIN), JX2.60 (VIN); also elsewhere on the board
/JX2_connections/IO_L6N_13: JX2.100 (IO_L6N_T0_VREF_13)
/JX2_connections/IO_L8N: JX2.43 (IO_L8N_T1_AD10N)
/JX2_connections/IO_L8P: JX2.41 (IO_L8P_T1_AD10P)
/JX2_connections/IO_L9N: JX2.37 (IO_L9N_T1_DQS_AD3N)
/JX2_connections/IO_L9P: JX2.35 (IO_L9P_T1_DQS_AD3P)
/JX2_connections/IO_L10N: JX2.44 (IO_L10N_T1_AD11N)
/JX2_connections/IO_L10P: JX2.42 (IO_L10P_T1_AD11P)
/JX2_connections/IO_L11N: JX2.49 (IO_L11N_T1_SRCC)
/JX2_connections/IO_L11P: JX2.47 (IO_L11P_T1_SRCC)
/JX2_connections/IO_L12N: JX2.50 (IO_L12N_T1_MRCC)
/JX2_connections/IO_L12P: JX2.48 (IO_L12P_T1_MRCC)
/JX2_connections/IO_L13N: JX2.55 (IO_L13N_T2_MRCC)
/JX2_connections/IO_L13P: JX2.53 (IO_L13P_T2_MRCC)
/JX2_connections/IO_L14N: JX2.56 (IO_L14N_T2_AD4N_SRCC)
/JX2_connections/IO_L14P: JX2.54 (IO_L14P_T2_AD4P_SRCC)
/JX2_connections/IO_L16N: JX2.63 (IO_L16N_T2)
/JX2_connections/IO_L16P: JX2.61 (IO_L16P_T2)
/JX2_connections/IO_L18N: JX2.69 (IO_L18N_T2_AD13N)
/JX2_connections/IO_L18P: JX2.67 (IO_L18P_T2_AD13P)
/JX2_connections/IO_L20N: JX2.75 (IO_L20N_T3_AD6N)
/JX2_connections/IO_L20P: JX2.73 (IO_L20P_T3_AD6P)
/JX2_connections/IO_L20_13_N: JX2.95 (IO_L20N_T3_13)
/JX2_connections/IO_L20_13_P: JX2.93 (IO_L20P_T3_13)
/JX2_connections/IO_L21N: JX2.83 (IO_L21N_T3_DQS_AD14N)
/JX2_connections/IO_L21P: JX2.81 (IO_L21P_T3_DQS_AD14P)
/JX2_connections/IO_L21_13_N: JX2.96 (IO_L21N_T3_DQS_13)
/JX2_connections/IO_L21_13_P: JX2.94 (IO_L21P_T3_DQS_13)
/JX2_connections/IO_L22_13_N: JX2.99 (IO_L22N_T3_13)
/JX2_connections/IO_L22_13_P: JX2.97 (IO_L22P_T3_13)
/JX2_connections/IO_L23N: JX2.89 (IO_L23N_T3), U3.1 (TXD)
/JX2_connections/IO_L23P: JX2.87 (IO_L23P_T3), U3.4 (RXD)
/JX2_connections/LED0: JX2.18 (IO_L2P_T0_AD8P), Q3.1 (G)
/JX2_connections/LED1: JX2.20 (IO_L2N_T0_AD8N), Q4.1 (G)
GND: C1.2, C2.2, C3.2, C4.2, C5.1, C6.2, C11.2, JX2.15 (GND), JX2.16 (GND), JX2.21 (GND), JX2.22 (GND), JX2.27 (GND), JX2.28 (GND), JX2.33 (GND), JX2.34 (GND), JX2.39 (GND), JX2.40 (GND), JX2.45 (GND), JX2.46 (GND), JX2.51 (GND), JX2.52 (GND), JX2.65 (GND), JX2.66 (GND), JX2.71 (GND), JX2.72 (GND), JX2.77 (GND), JX2.85 (GND), JX2.86 (GND), JX2.91 (GND), JX2.92 (GND), Q3.2 (S), Q4.2 (S), U3.5 (GND), U3.13 (GND), U7.T6 (GND), U8.T6 (GND); also elsewhere on the board
IO_L3N: JX2.25 (IO_L3N_T0_DQS_AD1N), U7.T2 (SCLK-)
IO_L3P: JX2.23 (IO_L3P_T0_DQS_AD1P), U7.B2 (SCLK+)
IO_L4N: JX2.26 (IO_L4N_T0), U7.T1 (_CS-)
IO_L4P: JX2.24 (IO_L4P_T0), U7.B1 (_CS+)
IO_L5N: JX2.31 (IO_L5N_T0_AD9N), U7.T4 (CIPO1-)
IO_L5P: JX2.29 (IO_L5P_T0_AD9P), U7.B4 (CIPO1+)
IO_L6N: JX2.32 (IO_L6N_T0_VREF), U7.T3 (COPI-)
IO_L6P: JX2.30 (IO_L6P_T0), U7.B3 (COPI+)
IO_L7N: JX2.38 (IO_L7N_T1_AD2N), U7.T5 (CIPO2-)
IO_L7P: JX2.36 (IO_L7P_T1_AD2P), U7.B5 (CIPO2+)
IO_L15N: JX2.64 (IO_L15N_T2_DQS_AD12N), U8.T1 (_CS-)
IO_L15P: JX2.62 (IO_L15P_T2_DQS_AD12P), U8.B1 (_CS+)
IO_L17N: JX2.70 (IO_L17N_T2_AD5N), U8.T2 (SCLK-)
IO_L17P: JX2.68 (IO_L17P_T2_AD5P), U8.B2 (SCLK+)
IO_L19N: JX2.76 (IO_L19N_T3_VREF), U8.T3 (COPI-)
IO_L19P: JX2.74 (IO_L19P_T3), U8.B3 (COPI+)
IO_L22N: JX2.84 (IO_L22N_T3_AD7N), U8.T4 (CIPO1-)
IO_L22P: JX2.82 (IO_L22P_T3_AD7P), U8.B4 (CIPO1+)
IO_L24N: JX2.90 (IO_L24N_T3_AD15N), U8.T5 (CIPO2-)
IO_L24P: JX2.88 (IO_L24P_T3_AD15P), U8.B5 (CIPO2+)
unnamed: D1.1 (K), R17.1
unnamed: D2.1 (K), R18.1
unnamed: D6.2 (A), R13.2
unnamed: D6.1 (K), U3.7 (CBUS2)
unnamed: D7.2 (A), R15.2
unnamed: D7.1 (K), U3.14 (CBUS1)
unnamed: Q3.3 (D), R17.2
unnamed: Q4.3 (D), R18.2
unnamed: C11.1, R13.1, R15.1, U3.3 (VCCIO), U3.10 (3V3OUT), U3.11 (~RESET)
unnamed: R4.2, U3.9 (USBDM)
unnamed: R3.2, U3.8 (USBDP)
unnamed: FB1.2, U3.12 (VCC)
PG_CARRIER: JX2.11 (PG_CARRIER), TP10.1; also elsewhere on the board
USB_D+: R3.1; also elsewhere on the board
USB_D-: R4.1; also elsewhere on the board
VCCIO_35: C4.1, C5.2, C6.1, D1.2 (A), D2.2 (A), JX2.78 (VCCIO_35), JX2.79 (VCCIO_35), JX2.80 (VCCIO_35), JX2.98 (VCCO_13); also elsewhere on the board
VCCIO_EN: JX2.10 (VCCIO_EN); also elsewhere on the board

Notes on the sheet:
Single-ended 50Ω
Diferential pairs 100Ω

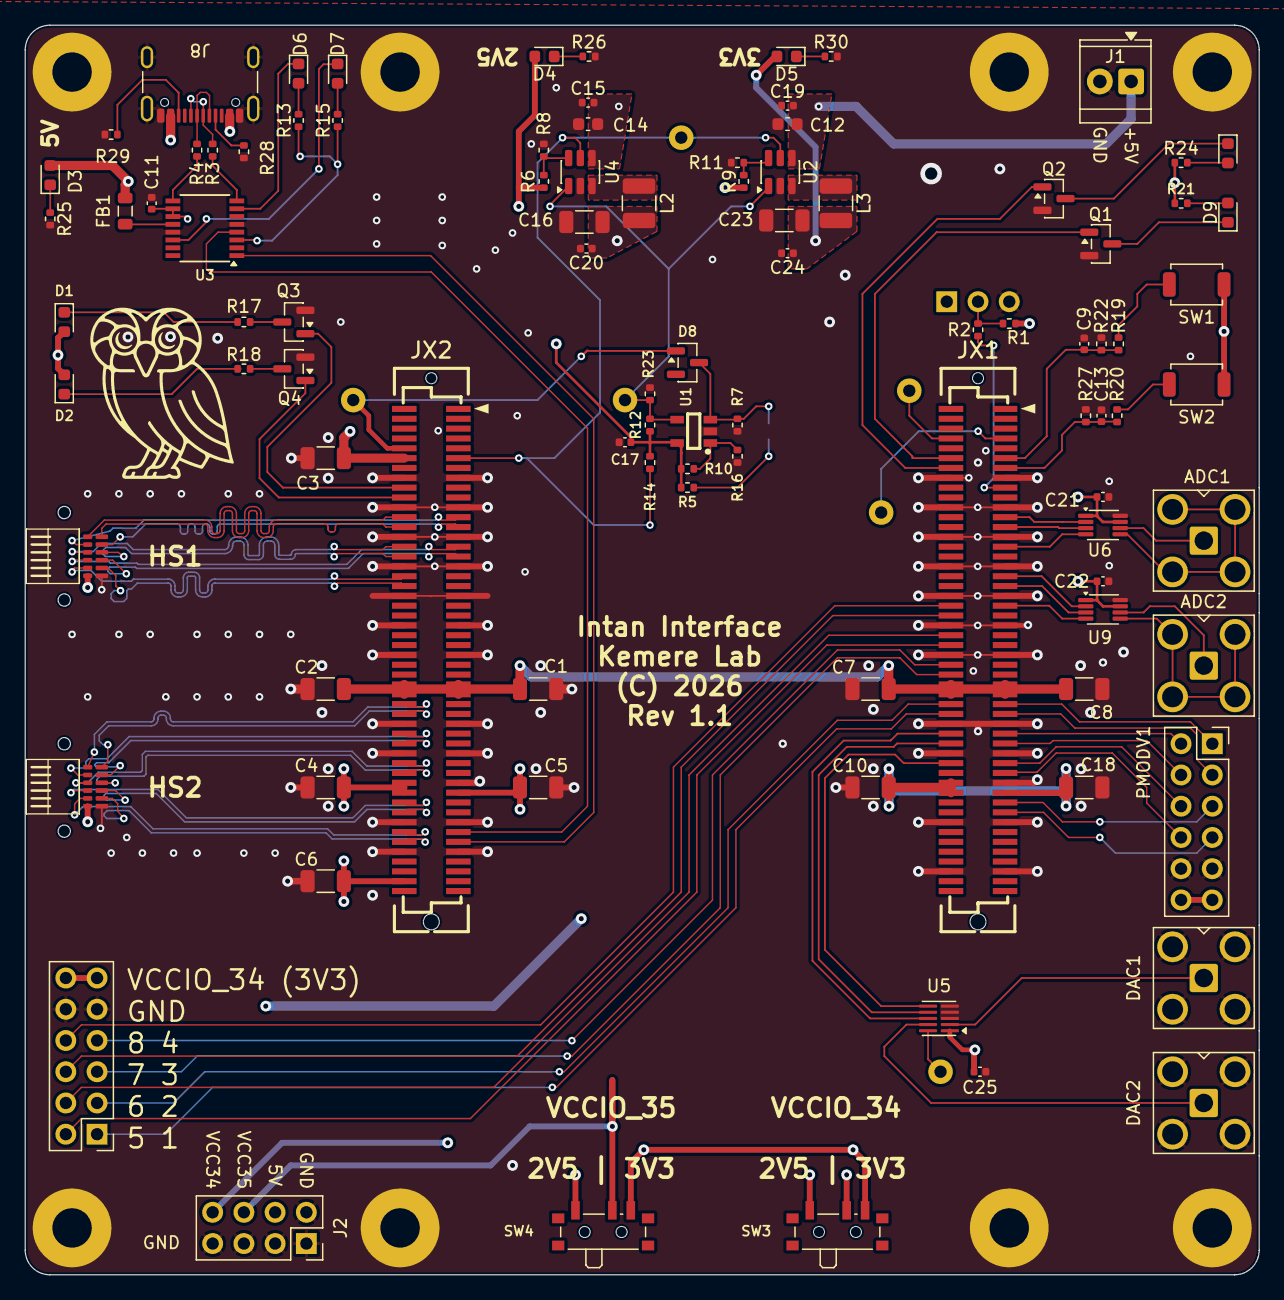
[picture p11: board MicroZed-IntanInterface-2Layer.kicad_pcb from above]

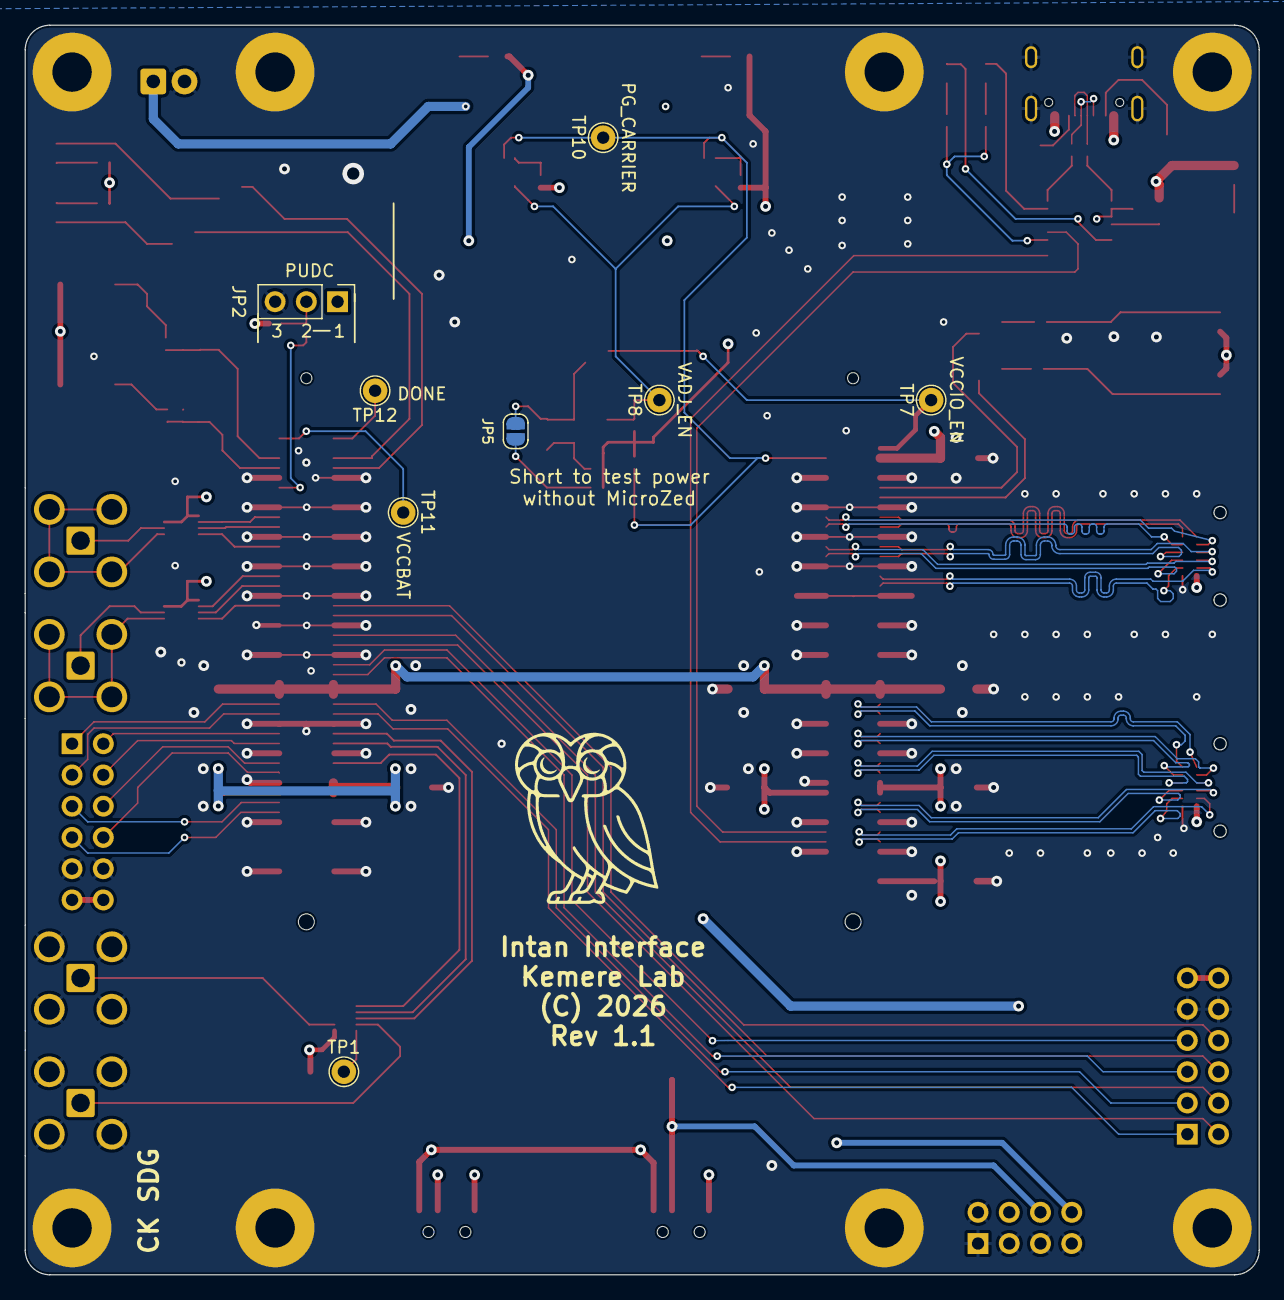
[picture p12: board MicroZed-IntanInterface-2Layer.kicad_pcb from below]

Board: 4 copper layers, 100.3 x 101.6 mm, 114 parts (9 on the bottom side), 105 nets.

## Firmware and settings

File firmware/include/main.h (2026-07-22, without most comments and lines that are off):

#define MAIN_H
#include <stdint.h>
#include "xparameters.h"
#include "xiltimer.h"
#include "lwip/udp.h"
#include "netif/xadapter.h"
#define UDP_PORT 0x6800   // 26624 -- unified data stream (broadband + LFP)
#define TCP_PORT 0x6900   // 26880 -- control channel
#define DEFAULT_UDP_DEST_IP_A   192
#define DEFAULT_UDP_DEST_IP_B   168
#define DEFAULT_UDP_DEST_IP_C   18
#define DEFAULT_UDP_DEST_IP_D   100
#define DEFAULT_UDP_DEST_PORT   0x6800   // 26624 (== UDP_PORT)
#define BEACON_PORT     0x6880   // 26752 -- discovery beacon (subnet broadcast)
#define BEACON_MAGIC    0x4B4C4231u   // distinctive discovery magic ("KLB1")
#define BEACON_VERSION  1
typedef struct {
    uint32_t magic;       // BEACON_MAGIC
    uint32_t version;     // BEACON_VERSION
    uint32_t ip;          // board IPv4, network byte order (== datagram source)
    uint16_t tcp_port;    // control port (TCP_PORT, 0x6900)
    uint16_t udp_port;    // unified data port (UDP_PORT, 0x6800)
    uint32_t fw_version;  // FIRMWARE_VERSION_WORD (maj<<24|min<<16|patch<<8|build)
    uint8_t  mac[6];      // board MAC = unique device id
    uint16_t reserved;    // pad to 28 bytes / 4-byte multiple
} device_beacon_t;
void beacon_init(void);   // create the beacon PCB + compute the broadcast addr
void beacon_send(void);   // broadcast one beacon (call ~1 Hz while link is up)
#define ARM1_BASEADDR 0xFFFFFFF0
#define ARM1_STARTADR 0x20000000
#define sev() __asm__("sev")
#define BRAM_BASE_ADDR          0x80000000
#define BYTES_PER_WORD          4           // 32-bit words
#define BRAM_SIZE_WORDS         16384       // 16384 x 32-bit words (64KB)
#define BRAM_SIZE_BYTES         (BRAM_SIZE_WORDS * BYTES_PER_WORD)   // 64KB
#define UNIFIED_MAGIC           0xCAFEBABE
#define UNIFIED_VERSION         1
#define UNIFIED_HEADER_WORDS    8
#define STREAM_TYPE_BROADBAND   1
#define STREAM_TYPE_LFP         2
#define STREAM_TYPE_WAVELET     3   // reserved for the follow-on branch
#define BB_SUBBLOCK_WORDS       6
#define PACKET_HEADER_WORDS     (UNIFIED_HEADER_WORDS + BB_SUBBLOCK_WORDS) // 14
#define MAX_PACKET_DATA_WORDS   140         // Maximum data words (all 8 streams = both ports)
#define MIN_PACKET_DATA_WORDS   18          // Minimum data words (1 stream enabled)
#define MAX_WORDS_PER_PACKET    (PACKET_HEADER_WORDS + MAX_PACKET_DATA_WORDS) // 154 words
#define MIN_WORDS_PER_PACKET    (PACKET_HEADER_WORDS + MIN_PACKET_DATA_WORDS) // 32 words
#define PL_CTRL_BASE_ADDR 0x40000000
#define PL_N_CTRL_REGS      28
#define CTRL_REG_0_OFFSET   (0 * 4)   // Enable transmission, reset timestamp, debug mode
#define CTRL_REG_1_OFFSET   (1 * 4)   // Loop count
#define CTRL_REG_2_OFFSET   (2 * 4)   // Phase select, channel enable
#define CTRL_REG_3_OFFSET   (3 * 4)   // Analytic chirp NCO config (see data_generator_core.sv)
#define CTRL_REG_MOSI_START_OFFSET  (CTRL_REG_0_OFFSET + (4 * 4)) // Offset for MOSI control words
#define CTRL_CHIRP_MODE          (1u << 0)
#define CTRL_CHIRP_STRIDE_SHIFT  2
#define CTRL_CHIRP_STRIDE_MASK   (0x3Fu << 2)
#define CTRL_CHIRP_FSPAN_SHIFT   8
#define CTRL_CHIRP_FSPAN_MASK    (0xFFFu << 8)
#define CTRL_CHIRP_RATE_SHIFT    20
#define CTRL_CHIRP_RATE_MASK     (0xFFFu << 20)
#define CTRL_REG_AUX_CTRL_OFFSET    (22 * 4)  // prog bank select + fast settle/digout/dsp config
#define CTRL_REG_AUX_WRITE_OFFSET   (23 * 4)  // write port payload (RT reg / program)
#define CTRL_REG_AUX_STROBE_OFFSET  (24 * 4)  // write/inject toggles + inject command
#define CTRL_REG_LFP_CFG_OFFSET     (25 * 4)  // [0]en [15:8]lane_mask [23:16]decim_R [31:24]num_taps
#define CTRL_REG_LFP_COEF_OFFSET    (26 * 4)  // [17:0] signed Q1.17 coefficient data
#define CTRL_REG_LFP_STROBE_OFFSET  (27 * 4)  // [0] coef write toggle, [1] coef pointer clear
#define LFP_STROBE_COEF_TOGGLE      (1u << 0)
#define LFP_STROBE_PTR_CLR          (1u << 1)
#define LFP_BRAM_BASE_ADDR          0x84000000
#define LFP_BRAM_SIZE_WORDS         16384      // 64 KB ring of 32-bit words (2x16-bit samples)
#define AUX_CTRL_BANK_BIT(slot)     (1u << (slot))   // slot == 0 -> reg22 bit 0
#define AUX_CTRL_BANK_SEL_MASK      (0x1u << 0)       // [0] only
#define AUX_CTRL_FS_SW              (1u << 4)  // software amp fast settle level
#define AUX_CTRL_FS_GPIO_EN         (1u << 5)
#define AUX_CTRL_FS_GPIO_SEL_SHIFT  6          // [8:6] digital_in pin select
#define AUX_CTRL_FS_GPIO_SEL_MASK   (0x7u << 6)
#define AUX_CTRL_DSP_SW             (1u << 9)  // software DSP-reset (CONVERT bit H) level
#define AUX_CTRL_DSP_GPIO_EN        (1u << 10)
#define AUX_CTRL_DSP_GPIO_SEL_SHIFT 11         // [13:11]
#define AUX_CTRL_DSP_GPIO_SEL_MASK  (0x7u << 11)
#define AUX_CTRL_DIGOUT_SW          (1u << 14) // software digout level
#define AUX_CTRL_DIGOUT_GPIO_EN     (1u << 15)
#define AUX_CTRL_DIGOUT_GPIO_SEL_SHIFT 16      // [18:16]
#define AUX_CTRL_DIGOUT_GPIO_SEL_MASK  (0x7u << 16)
#define AUX_CTRL_REG3_STATIC_SHIFT  24         // [31:24] RHD Reg-3 bits D7..D1 (D0 = live digout)
#define AUX_CTRL_REG3_STATIC_MASK   (0xFFu << 24)
#define AUX_WRITE_PACK(target, bank, is_len, addr, data) \
    ( ((uint32_t)(data) & 0xFFFFu)            | \
      (((uint32_t)(addr) & 0x3Fu)   << 16)    | \
      (((uint32_t)(target) & 0x3u)  << 22)    | \
      (((uint32_t)(bank) & 0x1u)    << 24)    | \
      (((uint32_t)(is_len) & 0x1u)  << 25) )
#define AUX_LENGTH_DATA(loop_idx, end_idx) \
    ( ((uint32_t)(loop_idx) & 0x3Fu) | (((uint32_t)(end_idx) & 0x3Fu) << 8) )
#define AUX_STROBE_WRITE_TOGGLE     (1u << 0)
#define AUX_STROBE_INJECT_TOGGLE    (1u << 1)
#define AUX_STROBE_INJECT_CMD_SHIFT 16         // [31:16] injected command (slot-2 one-shot)
#define AUX_BANK_ENTRIES            64
#define STATUS_REG_BASE      (PL_N_CTRL_REGS * 4)
#define STATUS_REG_0_OFFSET  (STATUS_REG_BASE + 0 * 4)   // Dynamic status + counters
#define STATUS_REG_1_OFFSET  (STATUS_REG_BASE + 1 * 4)   // Reflected control parameters
#define STATUS_REG_2_OFFSET  (STATUS_REG_BASE + 2 * 4)   // Packets sent
#define STATUS_REG_3_OFFSET  (STATUS_REG_BASE + 3 * 4)   // Timestamp low [31:0]
#define STATUS_REG_4_OFFSET  (STATUS_REG_BASE + 4 * 4)   // Timestamp high [63:32]
#define STATUS_REG_5_OFFSET  (STATUS_REG_BASE + 5 * 4)   // Loop count (registered)
#define STATUS_REG_6_OFFSET  (STATUS_REG_BASE + 6 * 4)   // Mirror of CTRL_REG_0 (enable, reset, etc.)
#define STATUS_REG_7_OFFSET  (STATUS_REG_BASE + 7 * 4)   // Mirror of CTRL_REG_1 (loop count)
#define STATUS_REG_8_OFFSET  (STATUS_REG_BASE + 8 * 4)   // Mirror of CTRL_REG_2 (phase select, debug mode)
#define STATUS_REG_9_OFFSET  (STATUS_REG_BASE + 9 * 4)   // Mirror of CTRL_REG_3 (reserved)
#define STATUS_REG_10_OFFSET (STATUS_REG_BASE + 10 * 4)  // BRAM write address + FIFO count (added by wrapper)
#define STATUS_REG_11_OFFSET (STATUS_REG_BASE + 11 * 4)  // Aux sequencer status
#define STATUS_REG_12_OFFSET (STATUS_REG_BASE + 12 * 4)  // Aux injected-command read result
#define STATUS_REG_13_OFFSET (STATUS_REG_BASE + 13 * 4)  // LFP: [15:0] BRAM wr byte-addr, [16] overrun
#define AUX_STATUS_BANK_ACTIVE_MASK  0x7u      // [2:0] active bank per slot (bit0=slot0 program)
#define AUX_STATUS_ENGINE_ON         (1u << 3) // always 1 (aux engine always on)
#define AUX_STATUS_FS_ACTIVE         (1u << 4)
#define AUX_STATUS_DIGOUT            (1u << 5)
#define AUX_STATUS_DSP_ACTIVE        (1u << 6)
#define AUX_STATUS_INJECT_ACK        (1u << 7) // toggles when an injection result lands
#define AUX_STATUS_IDX0_SHIFT        8         // [13:8]  slot-0 program index
#define AUX_STATUS_IDX1_SHIFT        16        // [21:16] slot-1 index (always 0: fs register)
#define AUX_STATUS_IDX2_SHIFT        24        // [29:24] slot-2 index (always 0: inject register)
#define AUX_STATUS_IDX_MASK          0x3Fu
#define RHD_CMD_CONVERT(ch)     ((uint16_t)(((ch) & 0x3F) << 8))
#define RHD_CMD_WRITE(reg, val) ((uint16_t)(0x8000 | (((reg) & 0x3F) << 8) | ((val) & 0xFF)))
#define RHD_CMD_READ(reg)       ((uint16_t)(0xC000 | (((reg) & 0x3F) << 8)))
#define CTRL_ENABLE_TRANSMISSION (1 << 0)
#define CTRL_RESET_TIMESTAMP     (1 << 1)
#define CTRL_DEBUG_MODE          (1 << 3)   // Debug mode (send dummy data) [3]
#define CTRL_PHASE0_MASK         (0xF << 0)   // phase_a0 [3:0]   (cable A, line 0)
#define CTRL_PHASE1_MASK         (0xF << 4)   // phase_a1 [7:4]   (cable A, line 1)
#define CTRL_PHASE2_MASK         (0xF << 8)   // phase_b0 [11:8]  (cable B, line 0)
#define CTRL_PHASE3_MASK         (0xF << 12)  // phase_b1 [15:12] (cable B, line 1)
#define CTRL_CHANNEL_ENABLE_MASK (0xFF << 16) // channel_enable [23:16]
#define CTRL_CHANNEL_ENABLE_SHIFT 16
#define STATUS_TRANSMISSION_ACTIVE   (1 << 0)
#define STATUS_LOOP_LIMIT_REACHED    (1 << 1)
#define STATUS_STATE_COUNTER_MASK    (0x7F << 3)  // [9:3] - 7 bits
#define STATUS_STATE_COUNTER_SHIFT   3
#define STATUS_CYCLE_COUNTER_MASK    (0x3F << 11) // [16:11] - 6 bits
#define STATUS_CYCLE_COUNTER_SHIFT   11
#define STATUS_ENABLE_TRANSMISSION_REG  (1 << 0)
#define STATUS_RESET_TIMESTAMP_REG      (1 << 1)
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

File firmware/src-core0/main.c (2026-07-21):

#include "main.h"
#include "platform.h"
#include "sleep.h"
#include <string.h>
#include <stdio.h>
#include "xil_io.h"
#include "xil_cache.h"
#include "lwip/init.h"
#include "lwip/timeouts.h"
#include "lwip/etharp.h"   // etharp_gratuitous() -- proactively refresh host ARP
//#include "xuartps.h"
#include "shared_print.h"
#include "pl_dma.h"
#include "xiltimer.h"  // XTime_GetTime / COUNTS_PER_SECOND for perf instrumentation

// Forward declare eth_link_detect from xemacpsif adapter
// This function is provided by the LWIP library's Xilinx EMAC adapter
extern void eth_link_detect(struct netif *netif);


// Global variables
XTimer timer;
struct netif server_netif;
struct udp_pcb *udp;
volatile int stream_enabled = 0;
uint32_t packets_received_count = 0;


// Link state tracking for hotplug support
volatile int link_is_up = 0;

// Command flags for main loop processing
volatile int enable_streaming_flag = 0;
volatile int disable_streaming_flag = 0;
volatile int reset_timestamp_flag = 0;
volatile int cable_test_flag = 0;

// BRAM state tracking
uint32_t ps_read_address = 0;              // Current PS read position (word address)
uint32_t staging_slot = 0;                 // rotating DDR staging-ring slot (zero-copy TX aliasing fix)
uint32_t current_packet_size = 84;         // 14-word header + 70 data words (0x0F default); recomputed on start
uint32_t current_channel_enable = 0x0F;    // Current channel enable setting (default all channels)

// Packet validation tracking
uint32_t error_count = 0;
uint32_t dma_errors = 0;   // CDMA read failures (BRAM_READ_DMA path)

// Performance instrumentation, observable via get_status. We store raw global-
// timer TICKS at full resolution and let the host convert to microseconds using
// perf_timer_hz (sent in the status) -- store the measurement, derive the
// display. The 30 kHz sample rate gives a 33.3 us budget per packet; loop_ticks
// is the receive->transmit time and dma_ticks is the CDMA transfer within it.
uint32_t dma_ticks_last = 0, dma_ticks_max = 0;     // CDMA transfer (ticks)
uint32_t loop_ticks_last = 0, loop_ticks_max = 0;   // receive->transmit (ticks)
uint32_t perf_timer_hz = 0;                         // tick freq (set in main())
// recv->transmit spike instrumentation. Split the recv->transmit window into the
// CDMA, udp_sendto, and "other" components so the host can attribute the
// occasional ~40 us spike; capture the worst packet's breakdown and a histogram
// + over-budget count for the tail's shape/frequency. Cleared by perf_reset().
uint32_t send_ticks_last = 0, send_ticks_max = 0;   // udp_sendto() call (ticks)
uint32_t over_budget_count = 0;                     // packets over the 33.3 us budget
uint32_t worst_pkt_index = 0;                       // packet idx of the worst loop
uint32_t worst_cdma_ticks = 0, worst_send_ticks = 0, worst_other_ticks = 0;
uint32_t loop_hist[PERF_HIST_BUCKETS] = {0};        // recv->transmit time distribution

// TX drop diagnostics (v1.6): split udp_send_errors by stream + failure mode and
// record WHEN drops happen. Each zero-copy PBUF_REF send holds one MEMP_PBUF
// entry (MEMP_NUM_PBUF, shared by broadband + LFP) until the GEM TX-done reaps
// it; pbuf_alloc()==NULL => that pool is momentarily empty. Declared before
// perf_reset() so it can clear them. Cleared by CMD_PERF_RESET.
uint32_t bb_pbuf_alloc_fail = 0, bb_send_err = 0;
int32_t  bb_last_send_err = 0;
// NO-LOSS retry stats (bb_send_err now = drops after exhausting all retries).
uint32_t bb_send_retries = 0, bb_pbuf_retries = 0, bb_send_recovered = 0;
uint32_t lfp_pbuf_alloc_fail = 0, lfp_send_err = 0;
int32_t  lfp_last_send_err = 0;
uint32_t first_drop_pkt = 0, last_drop_pkt = 0;
uint32_t drop_ring[8] = {0};
uint32_t drop_ring_idx = 0;
// If this fails, the wire layout changed -- update net.py get_status (the length
// check and the struct.unpack offsets) to match.
_Static_assert(sizeof(status_response_t) == 288, "status_response_t size must match net.py get_status");

// Clear the sticky maxes + worst-case snapshot + histogram + counts so the user
// controls the measurement window (CMD_PERF_RESET). Leaves the last-sample fields
// and dma_errors alone -- those self-refresh / are lifetime counters.
void perf_reset(void) {
  dma_ticks_max = 0;
  loop_ticks_max = 0;
  send_ticks_max = 0;
  over_budget_count = 0;
  worst_pkt_index = 0;
  worst_cdma_ticks = worst_send_ticks = worst_other_ticks = 0;
  for (int i = 0; i < PERF_HIST_BUCKETS; i++) loop_hist[i] = 0;
  // TX drop diagnostics
  bb_pbuf_alloc_fail = bb_send_err = 0; bb_last_send_err = 0;
  lfp_pbuf_alloc_fail = lfp_send_err = 0; lfp_last_send_err = 0;
  first_drop_pkt = last_drop_pkt = 0; drop_ring_idx = 0;
  for (int i = 0; i < 8; i++) drop_ring[i] = 0;
}

// Record a broadband TX drop (pbuf-alloc fail or udp_sendto error). packets_
// received_count is the count BEFORE this packet's increment, so the dropped
// packet is ~that index. first/last bracket the span; the ring shows clustering.
static void record_bb_drop(void) {
  uint32_t idx = packets_received_count;
  if (first_drop_pkt == 0) first_drop_pkt = idx;
  last_drop_pkt = idx;
  drop_ring[drop_ring_idx & 7u] = idx;
  drop_ring_idx++;
}

// UDP transmission
uint32_t udp_packets_sent = 0;
uint32_t udp_send_errors = 0;
// UDP configuration (can be changed via TCP command)
uint32_t udp_dest_ip = 0;      // Will be initialized in main()
uint16_t udp_dest_port = DEFAULT_UDP_DEST_PORT;

// Pre-allocated packet buffer for UDP (sized for maximum packet)
// Use __attribute__((aligned(64))) to align to cache line boundary for optimal performance
// Used as the packet buffer only on the BRAM_READ_SINGLE path; unused under DMA.
static uint32_t udp_packet_buffer[MAX_WORDS_PER_PACKET] __attribute__((aligned(64), unused));

// ---- Capture-BRAM read method ----------------------------------------------
// The PS M_AXI_GP master corrupts long *burst* reads of the capture BRAM (the
// 0xFF dual-port dropout). What we learned chasing it:
//   SINGLE - word-by-word Xil_In32. CLEAN by construction: each read is its own
//            1-beat AXI transaction, so it never issues the burst that the GP
//            master mishandles. But it is latency-bound and too slow to sustain
//            0xFF (256 ch, 150-word packets) at the 131.25 MHz AXI clock.
//            Raising the AXI clock to 210 MHz DID make single-beat fast enough --
//            but 210 MHz is over the -1 part's M_AXI_GP ~150 MHz spec
//            (clk_out2 also clocks the GP master), so it is bench-only, not
//            shippable. Kept here as the conceptual reference / fallback.
//   DMA    - an AXI CDMA (a PL master) copies each packet BRAM -> DDR over
//            S_AXI_HP0 (see pl_dma.c), taking the PS GP master off the bulk-read
//            path entirely. Clean at full bandwidth, in-spec at 131.25 MHz, and
//            it frees core 0. This is the fix. DEFAULT.
// (A removed third option, inline-`ldmia` chunked CPU bursts, was a burst over
//  the same broken GP master AND its asm scrambled word order -> wrong magic;
//  see git history. Don't reintroduce CPU bursts of the BRAM.)
#define BRAM_READ_DMA     0
#define BRAM_READ_SINGLE  1
#define BRAM_READ_METHOD  BRAM_READ_DMA

// ============================================================================
// PACKET SIZE CALCULATION FUNCTIONS
// ============================================================================

uint32_t calculate_data_words(int channel_enable) {
    int num_channels = 0;
    
    // Count enabled 16-bit streams across both ports (8-bit mask)
    for (int b = 0; b < 8; b++)
        if (channel_enable & (1 << b)) num_channels++;

    if (num_channels == 0) {
        send_message("WARNING: No channels enabled, defaulting to port-0 all channels\r\n");
        return 70; // Default to 4 streams (port 0) x 35 cycles / 2
    }
    
    // Calculate 32-bit words needed for the data
    // Each cycle produces num_channels × 16-bit words
    // Total 16-bit words = 35 × num_channels
    // Convert to 32-bit words with proper rounding up
    uint32_t total_16bit_words = 35 * num_channels;
    uint32_t data_32bit_words = (total_16bit_words + 1) / 2;  // Round up division
    
    return data_32bit_words;
}

uint32_t calculate_packet_size(int channel_enable) {
    return PACKET_HEADER_WORDS + calculate_data_words(channel_enable);
}

void update_current_packet_size(void) {
    uint32_t new_channel_enable = pl_get_current_channel_enable();
    
    if (new_channel_enable != current_channel_enable) {
        current_channel_enable = new_channel_enable;
        current_packet_size = calculate_packet_size(current_channel_enable);
        
        send_message("Updated packet size: channel_enable=0x%X, packet_size=%u words (%u bytes)\r\n",
                     current_channel_enable, current_packet_size, current_packet_size * 4);
    }
}

// ============================================================================
// BRAM ACCESS FUNCTIONS
// ============================================================================

int n_words_available;

// Check how many complete packets are available to read
static int packets_available(void) {
  uint32_t pl_write_addr = pl_get_bram_write_address();

  if (pl_write_addr >= ps_read_address) {
    n_words_available = pl_write_addr - ps_read_address;
  } else {
    // Handle wrap-around
    n_words_available = (BRAM_SIZE_WORDS - ps_read_address) + pl_write_addr;
  }

  // No guard band: the exposed write pointer (packet_boundary_address in
  // fifo_bram_interface.sv) advances ONLY at packet boundaries, so every packet
  // in [ps_read_address, pl_write_addr) is already fully committed -- the
  // in-progress packet is excluded by construction, so there is no
  // read-during-write to guard against. The CDC on that pointer is handled by the
  // read-twice deglitch in pl_get_bram_write_address(), and the per-packet magic
  // check is the safety net. (A former one-packet guard band here was a
  // misattributed band-aid for the M_AXI_GP burst corruption that the DMA fixed;
  // it also held back the last packet of any finite loop_count, so loop_count=1
  // streamed nothing.)
  return n_words_available / current_packet_size;  // complete packets available
}

// Read and validate one packet directly from BRAM with UDP transmission
static int process_packet_from_bram(void) {
  XTime t_loop0; XTime_GetTime(&t_loop0);   // perf: receive->transmit timer
  // Unified packet format: header word 0 = MAGIC (0xCAFEBABE), word 1 = TYPE_VER
  // with stream_type=1 (broadband), version=1 in the low 16 bits. The capture
  // BRAM only ever holds broadband packets (the LFP stream lives in its own
  // BRAM), so we validate both the magic AND the broadband stream_type/version.
  uint32_t magic_offset    = ps_read_address; // should always be < BRAM_SIZE_WORDS
  uint32_t typever_offset  = (ps_read_address + 1) % BRAM_SIZE_WORDS;

  uint32_t magic_word   = Xil_In32(BRAM_BASE_ADDR + (magic_offset * 4));   // DMA-EXEMPT: 2-word header peek (clean 1-beat reads; bulk payload moves by CDMA below)
  uint32_t typever_word = Xil_In32(BRAM_BASE_ADDR + (typever_offset * 4)); // DMA-EXEMPT: 2-word header peek (clean 1-beat reads; bulk payload moves by CDMA below)

  uint32_t expected_typever =
      (uint32_t)STREAM_TYPE_BROADBAND | ((uint32_t)UNIFIED_VERSION << 8);

  // Validate the unified header (magic + broadband type/version, low 16 bits)
  if (magic_word != UNIFIED_MAGIC ||
      (typever_word & 0xFFFFu) != (expected_typever & 0xFFFFu)) {
    // Invalid header - could be BRAM overflow, corruption, or misalignment.
    // Jump directly to write pointer to sync with fresh data.
    uint32_t pl_write_addr = pl_get_bram_write_address();
    ps_read_address = pl_write_addr;
    error_count++; // ERROR TO TRACK
    send_message("Header validation failed (magic=0x%08X type_ver=0x%08X), jumping to write position %u\r\n",
                 magic_word, typever_word, pl_write_addr);
    return 0; // Packet validation failed, now synced to fresh data
  }

  // TODO: If we are in an error state, we could track how long we stay there
  //    by measuring the timestamp gap when we recover.

  // UDP transmission (always enabled) - zero-copy with pre-allocated buffer.
  //
  // Read the packet out of the capture BRAM into pkt_buf (see "read method"
  // above). DMA: the CDMA copies BRAM -> a non-cacheable DDR buffer, split at
  // the BRAM wrap into two contiguous transfers. SINGLE: clean but slow
  // word-by-word Xil_In32 (the conceptual reference / 210 MHz fallback).
  uint32_t *pkt_buf;
#if BRAM_READ_METHOD == BRAM_READ_DMA
  // Staging RING: the send is zero-copy (PBUF_REF), so rotate the staging slot to
  // avoid clobbering a slot whose TX BD is still pending (see the broadband no-loss
  // notes). 128 * 2 KB = 256 KB inside the 1 MB pl_dma_staging.
  #define STAGING_SLOT_BYTES 2048u
  #define N_STAGING_SLOTS    128u
  pkt_buf = (uint32_t *)(DMA_BUF_ADDR + (uintptr_t)staging_slot * STAGING_SLOT_BYTES);
  staging_slot = (staging_slot + 1u) % N_STAGING_SLOTS;
  int derr;
  XTime t_dma0; XTime_GetTime(&t_dma0);     // perf: CDMA transfer timer
  if ((ps_read_address + current_packet_size) <= BRAM_SIZE_WORDS) {
    derr = pl_dma_read_bram(pkt_buf, ps_read_address, current_packet_size);
  } else {
    uint32_t first = BRAM_SIZE_WORDS - ps_read_address;
    derr  = pl_dma_read_bram(pkt_buf, ps_read_address, first);
    derr |= pl_dma_read_bram(pkt_buf + first, 0, current_packet_size - first);
  }
  XTime t_dma1; XTime_GetTime(&t_dma1);
  dma_ticks_last = (uint32_t)(t_dma1 - t_dma0);
  if (dma_ticks_last > dma_ticks_max) dma_ticks_max = dma_ticks_last;
  if (derr) dma_errors++;
#else  // BRAM_READ_SINGLE -- clean 1-beat reads, but too slow for 0xFF at 131 MHz
  pkt_buf = udp_packet_buffer;
  for (uint32_t i = 0; i < current_packet_size; i++) {
    uint32_t src = (ps_read_address + i) % BRAM_SIZE_WORDS;
    pkt_buf[i] = Xil_In32(BRAM_BASE_ADDR + src * 4);  // DMA-EXEMPT: BRAM_READ_SINGLE reference reader (compile-time fallback, not the default DMA path)
  }
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
int main() {
  ip_addr_t ipaddr, netmask, gw;
  unsigned char mac_ethernet_address[] = { 0x00, 0x0a, 0x35, 0x00, 0x01, 0x02 };

  init_platform();
  XilTickTimer_Init(&timer);
  perf_timer_hz = COUNTS_PER_SECOND;   // global-timer freq; host converts ticks->us

  // ========================================================================
  // NOTE: This applies to 1M of memory (see TRM - UG585)
  Xil_SetTlbAttributes(SHARED_MEM_BASE, NORM_NONCACHE_SHARED); // Critical for coherency!
  // The capture BRAM (0x80000000) is written by the PL behind the data cache.
  // Reading it cached lets the A9 prefetcher pull lines while the PL is mid-write,
  // and there is no invalidate in the streaming read path -> stale/garbage words
  // surface in the UDP stream (seen as out-of-range values near the tail cycles
  // of each packet, worse at the higher dual-port data rate). Map it
  // non-cacheable so every read goes to the PL's committed data.
  Xil_SetTlbAttributes(BRAM_BASE_ADDR, NORM_NONCACHE_SHARED); // PL writes behind the cache
  // Xil_SetTlbAttributes(PL_CTRL_BASE_ADDR, NORM_NONCACHE_SHARED);
  // Prepare for second core by initializing shared structures
  init_print_buffer();
  memset((void *)command_flags, 0, sizeof(command_flags_t));
  psmon_init();   // zero the status snapshot before core 1 reads it
  pl_rhd_shadow_init();   // seed the RHD register mirror from the init defaults
#if BRAM_READ_METHOD == BRAM_READ_DMA
  pl_dma_init();  // AXI CDMA + non-cacheable DDR staging buffer for the read path
#endif

  // Bring up the LFP/DSP engine with its baked-in default filter so LFP streams
  // out of the box (stream_type=2 on the unified port) with NO host configuration.
  // Default = CIC^4(/5) + halfband(/2) = /10 -> 3 kHz, using the 43-tap comp-FIR
  // baked into lfp_halfband's coef RAM. The host can still reconfigure the params
  // and coefficients (e.g. fewer taps for lower group delay) or disable at runtime.
  pl_lfp_set_config(/*enable=*/1, /*decim_R=*/10, /*num_taps=*/43);
  // ========================================================================

  // ========================================================================
  // Clean cache to make sure memory is visible to CPU1
  // Write the memory space base address in the Zynq's DDR (PS7 DDR) for ARM Core 1 to 
  //  0xFFFFFFF0 (which is 0x10080000 in this project).
  Xil_Out32(ARM1_BASEADDR, ARM1_STARTADR);
  // Flush the cache line containing the register write
  Xil_DCacheFlushRange(ARM1_BASEADDR, 4);
  // Full memory barriers to ensure ordering
  dmb();  // Data Memory Barrier
  dsb();  // Data Synchronization Barrier
  isb();  // Instruction Synchronization Barrier
  // ========================================================================

  xil_printf("GLANCE v%d.%d.%d.%d by the Kemere Lab\n\r\n\r\n\r",
            FIRMWARE_VERSION_MAJOR,
            FIRMWARE_VERSION_MINOR,
            FIRMWARE_VERSION_PATCH,
            FIRMWARE_VERSION_BUILD);

  // Initialize network
  IP4_ADDR(&ipaddr, 192, 168, 18, 10);
  IP4_ADDR(&netmask, 255, 255, 255, 0);
  IP4_ADDR(&gw, 192, 168, 18, 1);
  
  // NOTE: Something is suspect about our shared memory setup, in the sense
  //       that LWIP does something that breaks if we let the other core start
  //       before we call lwip_init. Is it LWIP's fault? Ours???

  // TODO: Figure out how to make this work with hotplug
  // TODO: Ideally, we'd allow for a DHCP option with some sort of discovery protocol
  lwip_init();
  
  netif_add(&server_netif, &ipaddr, &netmask, &gw, NULL, NULL, NULL);
  netif_set_default(&server_netif);
  xemac_add(&server_netif, &ipaddr, &netmask, &gw,
       mac_ethernet_address, XPAR_XEMACPS_0_BASEADDR);
  netif_set_up(&server_netif);
  service_network();   // RX is live now -- start draining it through the rest of init

  // Start second core
  xil_printf("ARM0: sending the SEV to wake up ARM1\n\r");
  sev(); // Send event to wake up ARM1
  usleep(5000);

  send_message("Debug server up and running.\r\n");
    
  // Interrogate PHY to detect initial link state right after xemac_add completes
  // We'll only start TCP and UDP if we're connected
  eth_link_detect(&server_netif);
  if (netif_is_link_up(&server_netif)) {
    link_is_up = 1;
    send_message("Network link UP at boot\r\n");
  } else {
    link_is_up = 0;
    send_message("Network link DOWN at boot - waiting for cable connection...\r\n");
  }

  while (!link_is_up) {
    service_network();   // keep draining RX while waiting for PHY link-up
    eth_link_detect(&server_netif);
    if (netif_is_link_up(&server_netif)) {
      link_is_up = 1;
      send_message("Network link UP\r\n");
    }
  }

  start_tcp_server();
  service_network();   // answer anything already waiting on the listener

  // Initialize UDP (always enabled)
  udp_stream_init();
  lfp_stream_init();   // LFP band shares the unified UDP port (UDP_PORT), stream_type=2

  send_message("Network initialized. IP: %s\r\n", ip4addr_ntoa(&ipaddr));
  
  // Initialize PL
  pl_set_transmission(0);
  pl_set_loop_count(0);
    
  // Initialize packet size based on current channel_enable setting
  update_current_packet_size();

  pl_set_copi_commands(initialization_cmd_sequence);
  service_network();   // keep the RX pool drained across PL init
  
  send_message("System ready. Commands: start, stop, reset_timestamp, status\r\n");
  send_message("debug> ");

  // Board is fully up now. Proactively announce our IP->MAC with a gratuitous
  // ARP so the host's ARP cache and the switch CAM learn us immediately -- the
  // direct antidote to the stale/failed-ARP "[Errno 64] Host is down" the host
  // reports when it connects before it has heard from us. Then emit ONE
  // unambiguous readiness line, distinct from the earlier "link UP"/"server up"
  // notices that fire >20 s before the board can actually service a connection.
  etharp_gratuitous(&server_netif);
  send_message("READY: safe to connect now (TCP command port %d up)\r\n", TCP_PORT);

  // Start the discovery beacon: from here we broadcast our identity ~1 Hz (in
  // network_maintenance_loop) so a client can auto-discover our IP and know we're
  // up, without sending us anything during boot. See beacon_send().
  beacon_init();

  // Main event loop
  while (1) {
    network_maintenance_loop();
    
    if (stream_enabled) {
      // Process all available packets with direct BRAM access and UDP transmission
      while (packets_available() > 0) { 
        process_packet_from_bram();
        
        // Periodic status (every 30k packets)
        if (packets_received_count % 30000 == 0) {
          send_message("Processed %u packets, %u errors, %u nwa, UDP: %u sent/%u errors\r\n",
               packets_received_count, error_count, n_words_available,
               udp_packets_sent, udp_send_errors);
        }
      }
    }
  }
  
  cleanup_platform();
  return 0;
}

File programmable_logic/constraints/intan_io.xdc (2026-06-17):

# Intan SPI LVDS Interface Constraints
# This file provides pin assignments and I/O standards for the LVDS SPI interface
# Modify the PACKAGE_PIN assignments to match your specific FPGA and PCB layout

#==============================================================================
# LVDS SPI Clock - Differential Pair
#==============================================================================
set_property IOSTANDARD LVDS_25 [get_ports spi_lvds_0_sclk_p]
set_property IOSTANDARD LVDS_25 [get_ports spi_lvds_0_sclk_n]
set_property PACKAGE_PIN E17 [get_ports spi_lvds_0_sclk_p]
set_property PACKAGE_PIN D18 [get_ports spi_lvds_0_sclk_n]

# Clock output timing constraints
# SPI controller runs on 84MHz clock, so all outputs are relative to this clock
# 24MHz SPI clock is generated by dividing the 84MHz controller clock
set_output_delay -clock [get_clocks clk_out1_design_1_clk_wiz_0_84M_175M_0] -max 2.0 [get_ports {spi_lvds_0_lvds_0_sclk_p spi_lvds_0_lvds_0_sclk_n}]
set_output_delay -clock [get_clocks clk_out1_design_1_clk_wiz_0_84M_175M_0] -min -2.0 [get_ports {spi_lvds_0_lvds_0_sclk_p spi_lvds_0_lvds_0_sclk_n}]
set_output_delay -clock [get_clocks clk_out1_design_1_clk_wiz_0_84M_175M_0] -max 2.0 [get_ports {spi_lvds_0_csn_p spi_lvds_0_csn_n}]
set_output_delay -clock [get_clocks clk_out1_design_1_clk_wiz_0_84M_175M_0] -min -2.0 [get_ports {spi_lvds_0_csn_p spi_lvds_0_csn_n}]
set_output_delay -clock [get_clocks clk_out1_design_1_clk_wiz_0_84M_175M_0] -max 2.0 [get_ports {spi_lvds_0_copi_p spi_lvds_0_copi_n}]
set_output_delay -clock [get_clocks clk_out1_design_1_clk_wiz_0_84M_175M_0] -min -2.0 [get_ports {spi_lvds_0_copi_p spi_lvds_0_copi_n}]
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

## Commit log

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2025-06-25 Reverted scatter gather DMA, register interface to basic 32-bit contorl and 32-bit status. Kept updated 84 MHz clock.
    [axi_control.v, data_generator.v]
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2025-07-26 Trying to start paring down xil_printf calls. No longer error if magic header missing. Added COPI array init.
    [main.c, main.h, network.c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]
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2025-08-13 First commit of 2 layer board. Note - there is a bug in the serial interface.
    [MicroZed-IntanInterface-2Layer.kicad_pcb, MicroZed-IntanInterface-2Layer.kicad_sch]
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2025-08-17 Control regs 0-3 are now mirrored back in status regs 6-9, with firmware updated to show them. Reworked status communications, but maybe in the end needed to turn off caching was the main problem.
    [axi_lite_registers.v, data_generator_core.sv, main.c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]
2025-08-17 Fixed bug where register reads weren't correctly prefixed by two MSB 1 bits
    [pl_control.c]
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2025-08-18 Updates - now correctly getting data from both cipo0 and cipo1. Also corrected loop 1 bug so that we now can receive a single packet.
    [data_generator_core.sv, main.c, pl_control.c]
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2025-08-29 Firmware updates. Converted network commands to binary format. Removed non-functional mosi-test-command-sequence. Fixed bug where ps_read_address was being set to zero wrongly.
    [main.c, main.h, net.py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]
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2025-10-30 Fixed bug where things went haywire if we reconfigured the channel enables.
    [main.c]
2025-11-01 Updated to add 3 more 64 bit words to header - so header is now 10 32b rather 4 32b. Digital IO in least significant 8 bits of first 64 bits. Fixed debug mode to be offset instead of twos complement.
    [data_generator_core.sv, main.h, net.py]
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2025-11-06 Add CMD_PING command for lightweight link status checking
    This adds a new TCP command (0x60) that provides a simple ping/keepalive
    mechanism without the overhead of send_message() calls. The ping command:
    - Returns a simple ACK response (3 bytes)
    - Does NOT call send_message() to avoid blocking during UDP streaming
    - Can be used to check link status at ~2Hz without affecting performance
    - Requires no parameters
    This addresses the issue where send_message() can lag packets during UDP
    streaming due to its 10ms timeout when waiting for the shared UART buffer.
    Changes:
    - firmware/src-core0/network.c: Added CMD_PING (0x60) definition and handler
    - remote/net.py: Added CMD_PING constant for cli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
    [net.py, network.c]
2025-11-06 Add ping command to net.py interactive shell
    Added a ping() helper function and "ping" command to the TCP control
    interface. This provides an easy way to test link status without
    affecting UDP streaming performance.
    The ping command:
    - Uses a fast 100ms timeout by default
    - Provides clear feedback on link status
    - Can be typed interactively in the TCP control shell
    - Uses the lightweight CMD_PING that doesn't call send_message()
    Usage in interactive shell:
    [TCP] Command: ping
    [TCP] Ping successful - link is up
    - Added ping() function with timeout parameter
    - Added "ping" command handler in tcp_control()
    - Updated help text to include ping command
    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
    [net.py]
2025-11-06 Fix ping() to trigger automatic reconnection on connection loss
    Removed internal exception handling from ping() function to allow
    socket.timeout and connection errors to propagate up to tcp_control()'s
    exception handler. This makes ping() behave consistently with other
    commands like get_status() - when the connection is lost, it now
    triggers the automatic reconnection logic.
    Before: ping() would catch exceptions and return False, never reconnecting
    After: ping() lets exceptions propagate, triggering reconnection
    This provides a consistent user experience across all commands.
    [net.py]
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2026-06-06 Make TCP keepalive setup cross-platform (fix macOS crash)
    socket.TCP_KEEPIDLE/TCP_KEEPINTVL/TCP_KEEPCNT are Linux-only and raised
    AttributeError on macOS. Consolidate the duplicated keepalive code into a
    configure_tcp_keepalive() helper that guards each platform-specific constant
    with hasattr() and falls back to TCP_KEEPALIVE (macOS) for the idle time.
    [net.py]
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2026-06-12 Integrate aux sequencer + override into datapath; firmware control; integration TB
    PL: sequencer + override instantiated inside data_generator_core (signal
    locality: cycle/state counters, cipo_data, digital_in all local). Command-
    source mux at cycles 32-34 gated by per-packet-latched aux_seq_en; DSP bit-H
    forcing on channel CONVERTs; header word 2 now carries {prev slot-3 echo,
    prev slot-2 echo, this slot-1 echo, aux flags, digital_in} (all-zero when
    disabled); one-shot injection result capture -> status reg 12 + ack toggle.
    Ctrl regs 22-24 (config / bank-write port / strobes+inject cmd), status regs
    11-12. N_CTRL 22->25, N_STATUS 11->13 (axi_lite_registers, wrapper, LED ctl).
    Fixed a late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
    [axi_lite_registers.v, data_generator_core.sv, main.h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]
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2026-06-12 Fix AXI-Lite write handshake deadlock (CPU wedge on skewed AWVALID/WVALID)
    The write FSM toggled awready/wready independently against their own
    valids and required all four ready/valid signals high in one cycle to
    accept. If the interconnect asserts AWVALID and WVALID one cycle apart
    (legal, traffic-dependent), the two readys oscillate in anti-phase and
    the accept condition is never true: the write is never performed, BVALID
    never asserts, and the ARM core hangs mid-store on the AXI-GP port -- no
    exception, no reset, silent serial console. Observed on hardware as a
    hard wedge during CMD_AUX_BANK_SELECT (first reproducible burst with the
    unlucky alignment; latent for all prior control writes)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
    [axi_lite_registers.v]
2026-06-12 DEBUG: breadcrumb prints in aux bank-select / upload path
    Brackets every AXI access in aux_strobe_write / pl_aux_select_bank /
    pl_aux_confirm_bank so the serial console pinpoints a hung transaction.
    REVERT after the AXI handshake fix is validated on hardware.
    [pl_control.c]
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2026-06-12 DEBUG: raw-UART char breadcrumbs across the whole TCP dispatch chain
    The send_message breadcrumbs have a blind spot (droppable when the ring
    is busy), and the previous trace shows pl_aux_select_bank likely never
    ran at all -- the wedge is upstream of the handler. dbgc() writes single
    chars straight to the UART TX FIFO (cannot be dropped, blocks only on
    UART drain): '{'/'}' = tcp_recv_cb entry/exit, '<X' = process_command
    entry with cmd-id low nibble, '>' = after send_ack, a/b/c/s =
    pl_aux_select_bank steps (read ctrl22 / write ctrl22 / send_message),
    d/e/f/g = pl_aux_confirm_bank steps, '~'/'!' = send_message ring-full
    wait / drop. BOOT.bin rebuilt (same fixed bitstream).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
    [network.c, pl_control.c, shared_print.c]
2026-06-12 Fix CPU wedge: misaligned cmd_packet_t into the TCP payload (LDRD fault)
    ROOT CAUSE of the aux bank-select hard wedge, found by disassembling the
    running ELF: process_command's bank-select case compiled (at -O3) to
    'ldrd r6, [r4, #12]' -- GCC legally merged the adjacent param1/param2
    loads into a load-doubleword. The cmd_packet_t* points directly into the
    lwIP pbuf payload, which sits at a halfword boundary (14-byte Ethernet
    header). Unaligned LDR is tolerated on the A9 (SCTLR.A=0), which is why
    the struct-cast 'worked' for years; LDRD alignment-faults on a non-word
    address REGARDLESS -> data abort -> abort handler spins -> dead network,
    dead console, power-cycle. Deterministic and client-in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
    [network.c]
2026-06-12 Remove debug instrumentation (wedge root-caused and fixed)
    Reverts the send_message breadcrumbs and the raw-UART dbgc char probes
    (bc75343 / 846aa83 instrumentation). The two real fixes stay: the
    aligned-command-copy in network.c (the actual wedge, 2b91204) and the
    AXI-Lite joint-accept handshake (c64574d). Clean BOOT.bin packed.
    [network.c, pl_control.c, shared_print.c]
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2026-06-13 Dual-port: decouple status reporting from the data pump (shared snapshot)
    Root-cause fix for 'get_status causes 2-7 packet errors during streaming':
    get_status called pl_print_status() -> 16 send_message() calls -> the print
    ring backed up -> send_message blocked up to 10ms -> core-0 data pump stalled
    -> BRAM overran (only ~3.6ms buffered at the dual-port packet size) ->
    corrupted packets. The blocking 'log' path was the problem, not the reads.
    New design (core 0 publishes, core 1 reads, no ring in the hot path):
    - psmon_t snapshot in the shared non-cacheable region; core 0 fills it every
    ~5ms with cheap PL-register reads + binary stores (seqlock-guarded), no
    string formatting, no UA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
    [main.c, network.c, shared_print.c]
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2026-06-17 feat: AXI-CDMA capture-BRAM read path; fixes 0xFF dual-port dropout (fw 1.1.0.0)
    The PS M_AXI_GP master corrupts long burst reads of the capture BRAM (the 0xFF
    dual-port dropout). Replace the CPU read with an AXI CDMA (a PL master) that copies
    each packet BRAM->DDR over S_AXI_HP0, taking the GP master off the bulk-read path.
    - BD: add axi_cdma_0 + enable S_AXI_HP0; smartconnect_1 becomes a 2x2 crossbar
    {GP1 (PS peeks), CDMA M_AXI} x {axi_bram_ctrl (BRAM), S_AXI_HP0 (DDR)}. WNS +0.44ns.
    - Firmware (pl_dma.c): XAxiCdma simple polled BRAM->non-cacheable DDR staging buffer
    (linker-reserved 1MB array, portable across DDR sizes) + boot self-test. main.c
    BRAM_READ_METHOD switch: DMA default,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
    [intan_io.xdc, main.c, main.h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]
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2026-06-18 fix: remove BRAM read guard band (broke finite loop_count; e.g. loop_count=1)
    The one-packet guard band in packets_available held the read pointer a full
    packet behind the write frontier. It was a misattributed band-aid for the
    M_AXI_GP burst corruption (now fixed by the DMA), and it is redundant: the
    exposed write pointer (packet_boundary_address) only advances at packet
    boundaries, so packets in [ps_read, write_addr) are already complete -- there is
    no read-during-write to guard against. The pointer CDC is handled by the
    read-twice deglitch in pl_get_bram_write_address(), and the per-packet magic
    check is the safety net. The guard band also held back the LAST packet of any
    finite acquisiti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
    [main.c]
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2026-06-18 PL: remap 8 digital inputs to new carrier rev GPIO routing
    digital_in_0[0..7] -> W16, V16, W20, V20, P20, N20, U19, U18 (the carrier GPIO
    header was re-routed in the latest PCB rev). New bitstream + BOOT.bin.
    TODO (schematic): the JX1 schematic SYMBOL is flipped, so the carrier net labels
    read 18N/18P,16N/16P,14N/14P,12N/12P but are actually 17N/17P,15N/15P,13N/13P,
    11N/11P. The FPGA pins are correct; the JX1 symbol and net labels should be
    corrected eventually so they match reality.
    [digital_inputs.xdc]
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2026-06-19 Bump firmware version 1.1 -> 1.2
    Reflects the cumulative feature work since 1.1: the AXI-CDMA bulk-read path,
    get_status configuration tracking (aux_ctrl + the RHD chip-register mirror),
    and fast-settle / DSP-reset / digout control via TTL/GPIO. get_status wire
    format is now 148 bytes. blobs/BOOT.bin rebuilt.
    [main.h]
2026-06-19 docs: correct channel count 128 -> 256 (dual-port = two cables x 128 ch)
    The dual-port datapath is two cables of up to 128 channels each = 256 channels
    at the full 0xFF config (8 streams x 32 ch). Several docs still described the
    old single-cable "128 ch" figure. Corrected in overview.txt, CLAUDE.md,
    README.md, docs/protocol.md, and a stale main.c comment. The data-rate numbers
    (~9 MB/s per cable, ~18 MB/s at full config) were already correct.
    Comment/doc-only; no binary change.
    [main.c]
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2026-06-20 LFP Tier-1: finalize PS streaming + host + blob (testable end-to-end)
    PL: expose the LFP output-BRAM write pointer + overrun in STATUS_REG_13
    (axi_lite_registers N_STATUS 13->14, wrapper). Rebuild closes timing WNS=+0.266.
    Firmware: PL_N_CTRL_REGS 25->28 (CRITICAL: fixes the status-reg base after the
    LFP control regs), LFP control regs + commands (0x80 enable / 0x81 params /
    0x82 channels / 0x83 coef-upload via the strobe window), core-0 lfp_stream_service
    that drains the LFP BRAM and emits a separate UDP stream on port 5001, get_status
    LFP fields (struct 148->160, _Static_assert). pl_control LFP config + coef helpers.
    Host (net.py): LFP command IDs, design_lfp_lowpass (windowed-sinc Q1.17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
    [axi_lite_registers.v, main.c, main.h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]
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2026-06-21 net.py: wire LFP (Tier-1) test commands into the interactive menu
    lfp_config/lfp_on/lfp_off/lfp_recv -- same fix as the bench commands: the LFP
    helpers needed the session sock and weren't reachable from the [TCP] prompt.
    [net.py]
2026-06-21 net.py: help command lists bench/LFP cmds; lfp_on warns if unconfigured
    The `help` response was missing the bench + LFP commands. Add them, with a note
    that lfp_config must run before lfp_on (default lane_mask is 0 = no streams). Also
    have lfp_on read back the mask and warn when it's 0, so "enabled but no data" is
    caught immediately.
    [net.py]
2026-06-21 net.py: robust LFP coef upload (longer timeout + stall report)
    lfp_config fires 128 synchronous WRITE_COEF round-trips at a 0.5s ack timeout;
    one stalling drops the TCP connection with a bare "timed out". Raise the
    per-coef timeout to 2s, check each ack, and on a stall print the exact tap index
    + how to tell a slow board from a wedged one (reconnect + ping).
    [net.py]
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2026-06-23 Chirp: pipeline the per-slot phase (multiply off the critical path)
    The CIC build's new critical path was cycle_counter -> chirp stride multiply ->
    sine LUT -> fifo_write_data (17 levels, WNS -0.55 ns) -- the chirp's
    channel_offset*stride multiply, which had margin in the dual-MAC build but went
    critical with the CIC placement. Register chirp_ch_phase (= phase_acc +
    slot*stride) off the current cycle_counter in its own stage; the 8 lane LUT reads
    + output mux (short) stay at state 77. cycle_counter + per-packet phase_acc are
    stable across a cycle, so the registered phase is the correct slot value before
    state 77.
    SIM: chirp_tb still bit-exact (1400 words PASS); aux identity PASS. Rebuild to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
    [data_generator_core.sv]
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2026-06-24 net.py: lfp_sweep -- chirp-driven measurement of the LFP anti-alias |H(f)|
    Adds measure_lfp_response() + _goertzel_power() and an interactive 'lfp_sweep'
    command. Drives the analytic chirp across [0, f_max], captures one LFP channel
    off UDP 5001, and per short window estimates the dominant frequency (Goertzel
    peak over a 25 Hz grid) + amplitude -> bins amplitude vs frequency = measured
    |H(f)|. Self-calibrating (no flat-chirp-spectrum assumption), pure-Python.
    Defaults: f_max=1490 (just under the 1500 Hz LFP Nyquist -> no folding),
    period=3, hop=64 so the swept tone hits every grid bin. Prints a dB table +
    ASCII plot + measured -3/-6/-20 dB crossings vs the predicted CIC+comp response.
    The cm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
    [net.py]
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2026-06-24 LFP: PL builds the whole wire packet in BRAM; PS just CDMAs it (no Xil_In32 loop)
    Make the LFP (Tier-1) PL->PS path fully DMA-correct, and mirror the LFP lane
    mask from the broadband channel-enable mask.
    PL (lfp_dsp_block.sv): build the COMPLETE LFP wire packet in the LFP output
    BRAM -- a 6-word header (0x1F1FBEEF / 0xCAFEBABE, 64-bit timestamp,
    lane_mask|(decim_R<<8)|(num_taps<<16)|(overrun<<24), seq) ahead of the
    decimated samples, so each BRAM frame is a full wire packet. A header-write
    micro-sequence triggered by the engine's frame_tick (= the decimation tick /
    start_pass, newly exposed from lfp_halfband.sv and lfp_fir_decimator.sv) writes
    the 6 header words at the frame base; the sampl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
    [data_generator_core.sv]
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2026-06-24 OCM staging: move CDMA<->Ethernet buffers off DDR (firmware v1.5)
    The perf instrumentation pinned the recv->transmit spike on DDR
    contention: the broadband CDMA stalls 4->44 us once a 2nd stream (LFP)
    loads the DDR controller, because the CDMA writes (BRAM->DDR staging)
    and the GEM TX reads (DDR->MAC) compete on the one DDR controller. With
    LFP on, over-budget packets jumped ~40x (0.0003% -> 0.012%).
    Fix: relocate both staging buffers from DDR (.bss) to the low 192 KB
    OCM (DMA_BUF_ADDR=0x1000, LFP_DMA_BUF_ADDR=0x2000), which the linker
    otherwise leaves entirely unused. The CDMA writes OCM over S_AXI_HP0
    (the HP0_DDR_LOWOCM segment reaches low OCM) and the GEM TX reads OCM --
    so the whole PL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
    [main.h]
2026-06-25 Revert "OCM staging: move CDMA<->Ethernet buffers off DDR (firmware v1.5)"
    This reverts commit c519267a412411a8e279a554bb486be36609451c.
    [main.h]
2026-06-25 Revert OCM + add TX-drop instrumentation (firmware v1.6)
    The OCM staging change (v1.5) did NOT help: CDMA max stayed ~41 us and
    over-budget was unchanged -- because the recv->transmit tail is EMAC
    TX-done ISR preemption, not DDR contention (confirmed: the worst packet
    was "other"=40 us, pure CPU time with no DMA/send in flight). So revert
    to the validated DDR-staging baseline (git revert of c519267).
    Separately, the host sees real drops: UDP Send Errors = 10 = 10 packets
    the board failed to transmit. That counter increments in our code when
    pbuf_alloc returns NULL or udp_sendto != ERR_OK -- i.e. the Ethernet TX
    side ran out of resources. Prime suspect from the BSP config:
    MEMP_NUM_PBUF = 16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
    [main.c, main.h, net.py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]
2026-06-25 lwIP TX headroom: n_tx_descriptors 64->256, mem_size 128K->256K (firmware v1.7)
    The v1.6 instrumentation showed the 10+2 drops were NOT the pbuf pool
    (pbuf_alloc-fail=0) but udp_sendto returning ERR_MEM -- the zero-copy
    PBUF_REF send path momentarily running out of a TX buffer descriptor
    and/or a heap header-pbuf during ISR-stall catch-up bursts. Drops were
    steady-state but ultra-rare (~12 in 2.85M, one per ~8 s) and spread
    across the run.
    Fix via supported BSP lwip220 config (create_vitis_project.py), NOT
    vendor-stack surgery: raise the two resources the zero-copy send needs:
    - n_tx_descriptors 64 -> 256 (TX BD ring; primary suspect)
    - mem_size 128K -> 256K (lwIP heap; header-pb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
    [main.h]
2026-06-25 net.py: persistent LFP UDP sink so the host never ICMP-storms the board
    Broadband-only is pristine (recv->transmit max 26.7us, 0 over-budget, 0
    drops); the spikes + ERR_MEM drops appear ONLY with lfp_on. Root cause is
    host-side: net.py's LFP receivers (receive_lfp / lfp_sweep) bind port 5001
    only transiently, so the rest of the time 5001 is unbound and the host
    kernel replies ICMP "port unreachable" to the board for every LFP datagram
    -- a ~3 kHz ICMP storm => ~3000 RX interrupts/s that preempt the board's
    polled loop. Broadband (5000) is always consumed -> no ICMP -> clean. That
    explains the asymmetry, why OCM didn't help (not DDR), and why "10% more
    packets" hurt so much (it's an RX-interr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
    [net.py]
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2026-06-28 PL: unified 8-word header for broadband + LFP, per-stream SEQ
    Reframe both PL packet builders to emit the common 8-word little-endian header
    from docs/unified-packet-format.md, with a per-stream monotonic sequence number
    in word 4 (NEW for broadband). NO DATA LOSS: every old broadband-header field is
    preserved (the data words are byte-identical; only the framing changed).
    data_generator_core.sv (broadband, stream_type=1):
    14-word header (8 common + 6 broadband sub-block), written as 7 x 64-bit FIFO
    header writes (states 0..6 of cycle 0):
    w0 MAGIC=0xCAFEBABE | w1 TYPE_VER=1|ver<<8|flags<<16
    w2/w3 timestamp | w4 SEQ (broadband per-stream, +1/packet, resets on start)
    w5 AUX0=ch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
    [data_generator_core.sv]
2026-07-05 firmware: fix permanent TCP/RX wedge from an early SYN during boot link-up
    Root cause: xemac_add() enables the interrupt-driven GEM RX, then boot spins in
    `while(!link_is_up)` calling only eth_link_detect -- never xemacif_input /
    sys_check_timeouts. Packets arriving in that window (an early client's SYN
    retries + ARP) pile up in recv_q; PBUF_POOL (256) exhausts; setup_rx_bds stops
    refilling the RX BD ring; the Zynq-7000 GEM hits its RX-used-bit hang errata.
    The only recovery (resetrx_on_no_rxdata) is driven by RX-done interrupts (a dead
    RX raises none) and its periodic timer is #if !NO_SYS -- compiled out of this
    bare-metal build -- so the MAC RX stays halted until power-cycle. Matches all
    s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
    [main.c]
2026-07-05 Revert "firmware: fix permanent TCP/RX wedge from an early SYN during boot link-up"
    This reverts commit 7c8a18ca8002c53b3736be757c46939ccf251546.
    [main.c]
2026-07-05 net.py: robust TCP connect with retry instead of hang/EHOSTDOWN crash
    The board takes >20 s after power-on to bring up its lwIP listener, and while
    booting (or if its GEM RX has wedged) it does not answer. A plain blocking
    connect() then either hangs ~75 s (macOS default connect timeout) or, once the
    host ARP entry ages out and re-resolution fails, crashes with
    '[Errno 64] Host is down' (EHOSTDOWN). None of those mean give-up.
    Replace the single blocking connect() (initial + reconnect paths) with
    connect_with_retry(): short per-attempt timeout, retry on the 'board not ready'
    errno family (ECONNREFUSED/EHOSTDOWN/EHOSTUNREACH/ETIMEDOUT/ENET*), symbolic so
    it's correct on both macOS and Linux.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
    [net.py]
2026-07-05 firmware(hypothesis): gratuitous ARP + accurate READY line
    Targets your ARP hunch from the board side and fixes the misleading readiness
    message. On full boot and on every hotplug link-up the board sends a gratuitous
    ARP so the host's ARP cache and switch CAM learn our IP->MAC immediately -- so a
    host connecting right after we're ready already has our MAC instead of sitting on
    a failed ARP ('Host is down'). Adds one unambiguous
    'READY: safe to connect now (TCP command port N up)' line, emitted only at true
    end of init, distinct from the earlier notices that fire >20 s too early.
    Independent of the servicing/diag branches (no RX-path changes) so it isolates
    cleanly. Note: if the board's RX i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
    [main.c]
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2026-07-06 fix: discovery timeout (8s) was shorter than boot -> gave up + hammered board
    Two coupled bugs behind 'no beacon + Host is down' on real hardware:
    1) net.py discovery waited only 8 s, but the board beacons only at the END of its
    >20 s boot -- so net.py stopped listening before the beacon ever started, then
    fell back to a TCP connect that poked the board DURING its un-serviced boot
    window (the RX-wedge trigger). Fix: BEACON_DISCOVERY_TIMEOUT 8 -> 30 s (must
    exceed boot), poll in 3 s slices with '...still listening' progress, and treat
    the beacon as the readiness gate. Set to 0 to skip (old fw / blocked port).
    2) The final branch had NO boot-time RX servicing (I left it o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
    [main.c, net.py]
2026-07-06 net.py: make discovery survive the board interface appearing mid-discovery
    Root cause of 'works on RESET but hangs in DISCOVERY on USB-C power-cycle': a
    power-cycle takes the Mac's board-facing Ethernet adapter DOWN then UP (reset
    keeps it up). discover_board bound ONE socket up front; a socket bound while that
    interface is down does not reliably receive its broadcasts once it returns
    (especially with another network also present), so the beacon is never seen.
    Fix: re-create + re-bind the listening socket every ~5 s across the discovery
    window, so a fresh bind picks up the interface once it's back. Also print, each
    cycle, the local IP that would route to the board (a pure route lookup, no p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
    [net.py]
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

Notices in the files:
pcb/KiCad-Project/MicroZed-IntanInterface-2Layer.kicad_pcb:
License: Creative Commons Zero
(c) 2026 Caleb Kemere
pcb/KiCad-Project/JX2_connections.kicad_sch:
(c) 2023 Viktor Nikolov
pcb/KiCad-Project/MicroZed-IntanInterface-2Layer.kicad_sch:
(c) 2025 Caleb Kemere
